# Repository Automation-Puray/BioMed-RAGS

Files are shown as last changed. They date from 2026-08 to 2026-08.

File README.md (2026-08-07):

# BioMed-RAGS

**A Low-Cost Open-Source Robotic Platform for Automated Optical Characterization of Complex Light Emitters**

> **Repository status:** This is a public pre-release repository. Hardware files, software, datasets, and supporting documentation are being reviewed and added progressively. The first complete versioned research release is not yet available.

## Overview

BioMed-RAGS is a low-cost, modular robotic platform for repeatable, spatially resolved characterization of optical emitters with different geometries. It supports cylindrical axial-azimuthal measurements and planar raster measurements using programmable scan paths and interchangeable detectors.

In the demonstrated configuration, a robotic arm and linear rail provide four controlled degrees of freedom for detector positioning. Two synchronized rotational stages provide a coordinated specimen-rotation axis for cylindrical measurements. The Python software coordinates motion, spectral acquisition, HDF5 data storage, processing, and visualization.

Device-specific drivers separate the measurement logic from the connected hardware, allowing sensors or motion components to be changed without rebuilding the complete control workflow.

## Demonstrated applications

The platform was evaluated using:

- Two light-diffusing fiber constructions for photodisinfection research
- A planar resin-printer backlight measured at multiple drive settings
- A bioreactor tube irradiance-mapping application example

## Key capabilities

- Automated cylindrical axial-azimuthal scanning
- Automated planar raster scanning
- Spatially resolved spectral-irradiance measurements
- Programmable scan ranges and step sizes
- Automatic spectrometer exposure adjustment
- Synchronized motion and spectral acquisition
- HDF5 storage of spectra and measurement coordinates
- Modular hardware-driver architecture
- Automated data processing and visualization
- Repeatability and reproducibility analysis

## Reported performance

| Measurement | Reported result |
|---|---:|
| Fiber peak irradiance, combined RSD | 1.21% (95% CI: 0.85–1.65%) |
| Planar area-mean irradiance, combined RSD | 0.78% (95% CI: 0.48–2.04%) |
| Fiber decay constant, combined RSD | 0.52% |
| Spectral peak stability across one 336-point scan | 0.06 nm |

These results describe the precision of the demonstrated measurement system. The study primarily evaluates repeatability and reproducibility rather than independent verification of absolute irradiance accuracy.

## Demonstrated configuration and cost

The demonstrated system uses a robotic arm on a 1000 mm linear rail, two synchronized rotational stages, a Raspberry Pi controller, and a spectrometer probe with a cosine corrector.

The automation layer used in this implementation cost approximately **USD 2,200**. This value is specific to the selected hardware and may change with component choice. The spectrometer, excitation source, and shared laboratory instruments are not included in this automation-layer estimate.

## Repository contents

| Directory | Contents |
|---|---|
| [`hardware/`](hardware/) | Bill of materials, mechanical designs, assembly photographs, and electronics documentation |
| [`firmware/`](firmware/) | Firmware and setup information for the rotational stages |
| [`software/`](software/) | Measurement-control and data-analysis software |
| [`data/`](data/) | Measurement datasets and processed results |
| [`docs/`](docs/) | Build, operation, calibration, and uncertainty documentation |
| [`examples/`](examples/) | Additional application examples and associated analyses |

These directories are currently being populated. Refer to the README inside each directory for its planned organization.

## Associated publication

This repository accompanies the manuscript:

> *A Low-Cost Open-Source Robotic Platform for Automated Optical Characterization of Complex Light Emitters*

The complete citation, DOI, and publication link will be added when they become available.

## Safety

This research platform includes moving robotic equipment and optical radiation sources. Appropriate laser or UV eye protection, beam control, access restriction, electrical precautions, and mechanical risk controls must be established before operation. Read the complete [platform safety guidance](SAFETY.md) before assembling or operating the system.

This repository does not replace a laboratory-specific risk assessment or the operating instructions supplied by equipment manufacturers.

## Credits and acknowledgements

The robotic arm control in this project uses the **pydexarm** Python library to communicate with the Rotrics DexArm. The DexArm firmware is built on [**Marlin**](https://marlinfw.org/), the open-source 3D-printer firmware project. DexArm firmware is fully open-source and its control commands (G-code) are compatible with Marlin.

- Marlin firmware: [marlinfw.org](https://marlinfw.org/) — GNU General Public Licence
- Rotrics DexArm: [rotrics.com](https://rotrics.com)
- pydexarm library: [github.com/Rotrics-Dev/pydexarm](https://github.com/Rotrics-Dev/pydexarm)

We thank the Marlin and Rotrics communities for making open robotic hardware accessible to research laboratories.

## License and citation

License files and `CITATION.cff` metadata are being prepared and will be included before the first complete versioned release.

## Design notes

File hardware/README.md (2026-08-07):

# Hardware

This directory contains the BioMed-RAGS bill of materials, mechanical design files, assembly photographs, and electronics documentation.

Planned organization:

- BOM/ — bill of materials
- mechanical/CAD/ — printable parts and assembly models
- mechanical/assembly_photos/ — approved assembly photographs
- electronics/ — wiring and electronic-component documentation

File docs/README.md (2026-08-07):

# Documentation

This directory contains the BioMed-RAGS build, operation, calibration, and measurement-uncertainty documentation.

Planned organization:

- `build_guide/`
- `SOP/`
- `calibration/`
- `uncertainty_budget.pdf`

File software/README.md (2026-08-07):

# Software

This directory contains the BioMed-RAGS measurement-control and data-analysis software.

The software will be organized into:

- `control/` — measurement control, hardware drivers, data storage, and calibration
- `analysis/` — data processing, precision analysis, and visualization

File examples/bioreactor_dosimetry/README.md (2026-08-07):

# Bioreactor dosimetry example

This directory will contain the approved example data and analysis materials for the bioreactor dosimetry application.

# Bioreactor tube dosimetry

The planar scanning workflow was applied to evaluate two different serpentine glass-tube configurations for a bioreactor using two 222 nm excimer lamps. Both tubes had a 4 mm outer diameter but followed different paths across the irradiated area.

A 220 × 160 mm irradiance field was measured over the 200–240 nm band at 2 × 2 mm resolution and a 10 mm standoff. The measured field was then registered to the CAD-defined centreline of each tube to estimate the irradiance experienced along its path.

The first tube had an evaluated path length of 1366 mm and a mean centreline irradiance of 686 µW/cm². The second tube had an evaluated path length of 1254 mm and a mean centreline irradiance of 780 µW/cm². This application demonstrates how the same planar measurement can be combined with different tube geometries to produce design-specific optical-dose information.

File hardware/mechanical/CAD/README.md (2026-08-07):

# Mechanical CAD files

This directory contains the mechanical design files for the BioMed-RAGS platform.

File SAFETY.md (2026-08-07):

# Safety

BioMed-RAGS is a research platform containing motorized equipment, electrical components, and optical radiation sources. It must be operated only by trained personnel following the applicable institutional risk assessment, local safety procedures, and manufacturer instructions.

The information in this document does not replace source-specific laser or UV safety assessment, laboratory training, or equipment manuals.

## Main hazards

The principal hazards include:

- Direct or reflected exposure to laser or ultraviolet radiation
- Eye or skin exposure during alignment, mounting, or testing
- Pinch, impact, and entanglement hazards from the robotic arm, linear rail, and rotational stages
- Unexpected motion caused by incorrect coordinates, units, limits, or software configuration
- Electrical hazards from power supplies, controllers, motors, and modified wiring
- Movement or release of an incorrectly secured specimen, detector, fixture, or cable

## Before operation

Before starting a measurement:

1. Identify the wavelength, optical power, operating mode, and hazard classification of the installed source.
2. Complete a risk assessment appropriate to the source and experimental configuration.
3. Restrict access to the measurement area as required by laboratory procedures.
4. Inspect the robot, rail, stages, fixtures, fasteners, wiring, and cables for damage or insecure connections.
5. Confirm that the specimen and detector are securely mounted.
6. Verify the coordinate system, scan limits, step direction, standoff distance, and expected motion.
7. Perform a low-speed dry run with the optical source disabled.
8. Confirm that an accessible method is available to stop motion and disconnect power.
9. Remove loose objects from the motion area and secure loose clothing, hair, and cables.
10. Do not leave the operating system unattended unless the laboratory risk assessment explicitly permits it.

## Optical radiation safety

The demonstrated applications include a 405 nm diode laser and measurements involving 222 nm excimer lamps. Direct or reflected optical radiation may cause eye or skin injury. Far-UVC radiation must not be assumed to be harmless.

Apply controls appropriate to the installed source, which may include:

- Enclosing or shielding the optical path
- Terminating beams with a suitable beam stop
- Preventing unintended reflections
- Restricting access during operation
- Using interlocks where required
- Monitoring the experiment remotely
- Wearing eye or skin protection selected for the wavelength and exposure level

Protective eyewear must have a wavelength range and optical density appropriate to the specific source. Eyewear does not replace enclosure, shielding, access control, or other engineering controls.

Switch off or otherwise make the optical source safe before installing, removing, or adjusting a specimen or detector. Alignment with an active source should be performed only under an approved alignment procedure.

## Robotic and mechanical safety

The robotic arm, linear rail, and rotational stages can create pinch, impact, and entanglement hazards.

- Keep hands and other objects outside the motion envelope while the system is enabled.
- Disable motion and disconnect power before adjusting fixtures or mechanical components.
- Do not exceed the travel, speed, payload, or operating limits specified by the equipment manufacturers.
- Secure specimens at both ends before operating the rotational stages.
- Route cables so they cannot become trapped, stretched, or wound around moving components.
- Use conservative speeds during setup and after any hardware or software change.

The demonstrated rotational stages operate open loop. A missed motor step may not be detected automatically. Verify the mechanical reference position before a scan and after any unexpected interruption or collision.

## Software and motion configuration

Software limits are not physical guards.

Before enabling automated motion:

- Check that all coordinates use the intended units and reference frame.
- Confirm minimum and maximum positions for every axis.
- Check the sign and direction of each step value.
- Confirm that the programmed path cannot contact the specimen, fixtures, optical table, or nearby equipment.
- Test the stop procedure before the first active measurement.
- Repeat the dry run after changing fixtures, detectors, scan geometry, or control software.

Stop the system immediately if movement differs from the expected path.

## Electrical safety

- Disconnect power before modifying wiring or electronics.
- Do not operate the system with exposed conductors or damaged cables.
- Use suitable power supplies, protective enclosures, connectors, strain relief, and overcurrent protection.
- Follow the grounding and installation requirements provided by each equipment manufacturer.
- Electrical modifications should be performed only by personnel qualified for the work.

## Incident response

If unintended exposure, collision, electrical failure, mechanical damage, or abnormal motion occurs:

1. Stop motion and disable the optical source.
2. Disconnect power when it is safe to do so.
3. Prevent further access to the affected equipment.
4. Follow the laboratory incident and medical-response procedures.
5. Inspect and revalidate the system before returning it to operation.

Report safety-related repository issues without including personal, confidential, or security-sensitive information.

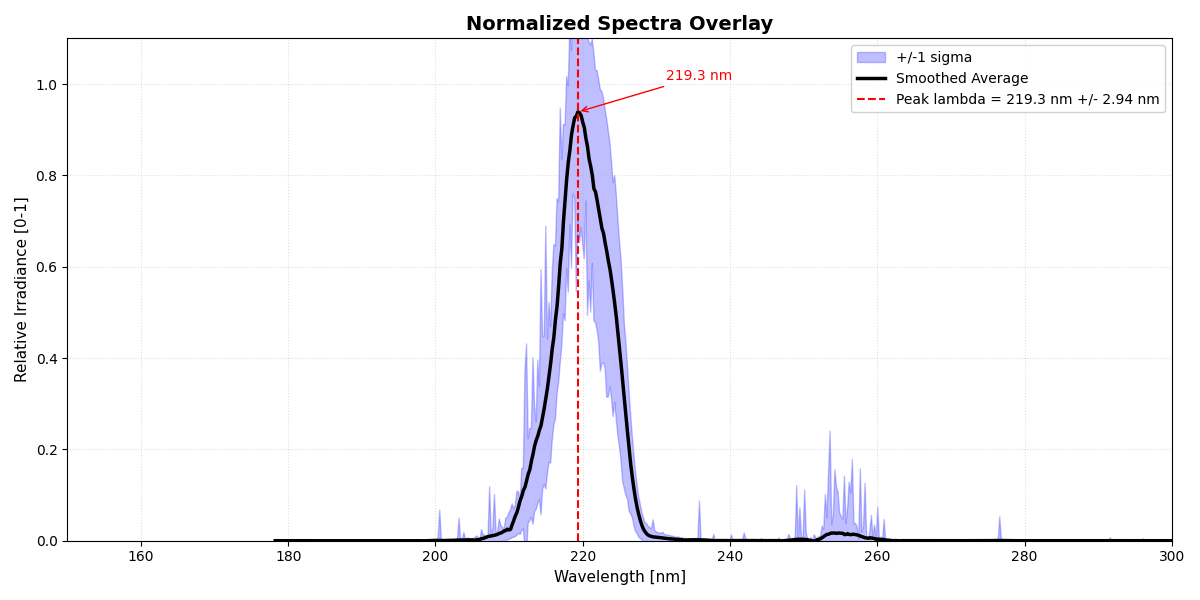
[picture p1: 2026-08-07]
examples/bioreactor_dosimetry/2x2_Spectral_Overlay.png

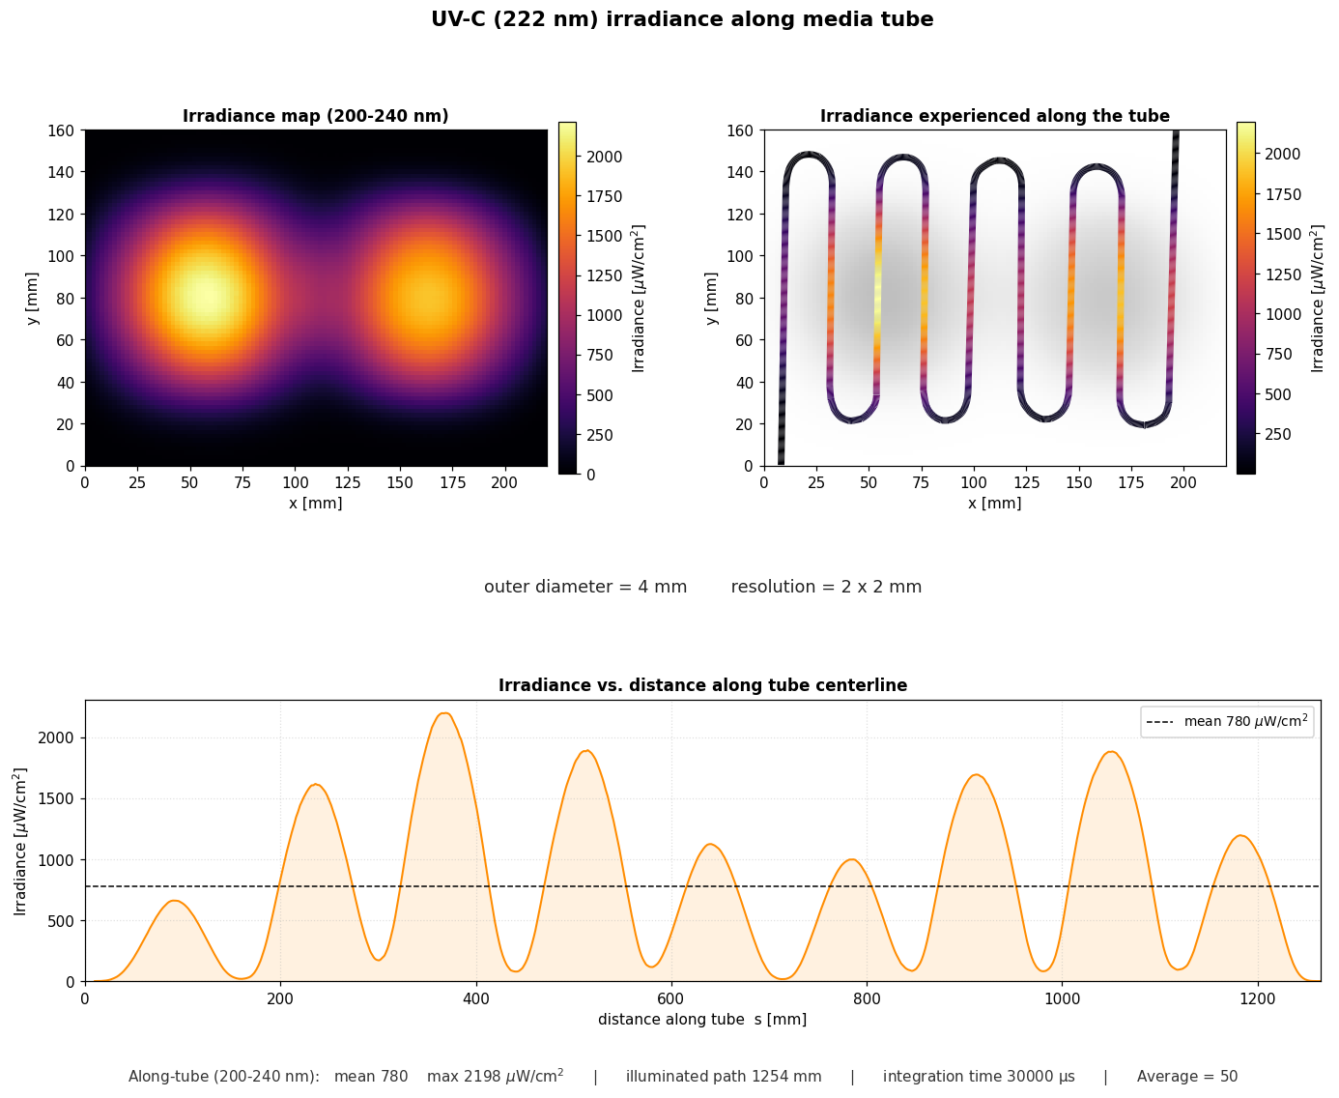
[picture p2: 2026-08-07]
examples/bioreactor_dosimetry/2x2_Plate_2.png

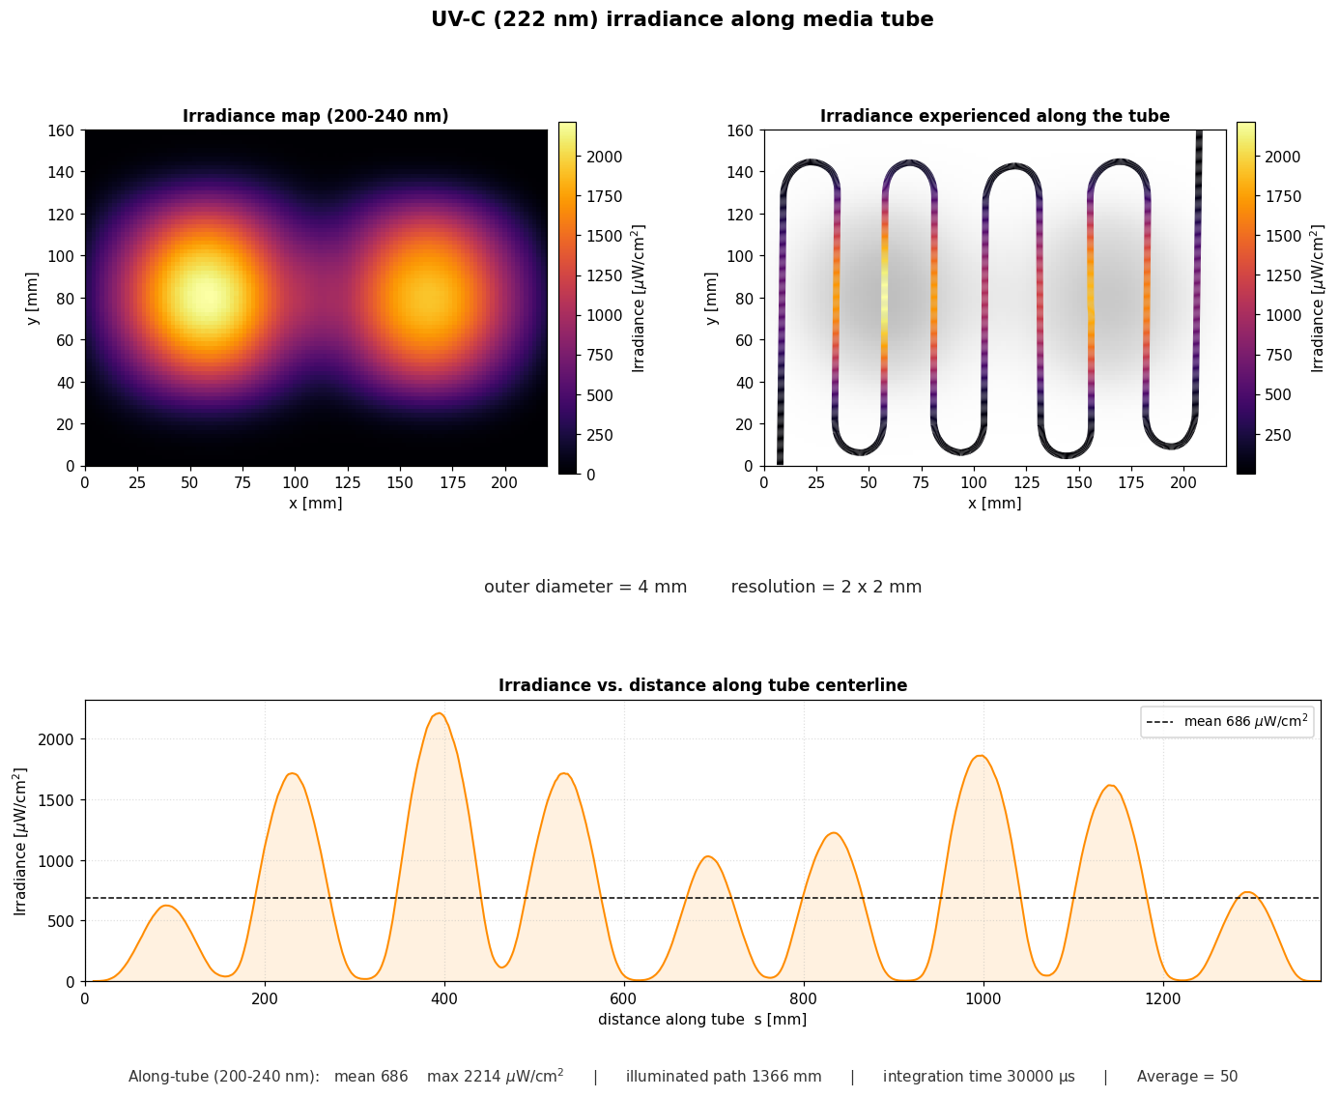
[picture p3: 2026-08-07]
examples/bioreactor_dosimetry/2x2_Plate_1.png

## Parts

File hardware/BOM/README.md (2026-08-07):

Bill of Materials

The Excel BOM lists the components and approximate 2025-2026 costs for the demonstrated BioMed-RAGS configuration.

Cost context

The full-system total is not a minimum build cost. The new automation hardware in the demonstrated setup costs approximately USD 2,200. Actual reproduction costs depend on the equipment already available and the hardware selected.

Many optics and engineering laboratories may already have common components such as:

a calibrated spectrometer;

an optical breadboard;

a laser source;

optical posts and mounts;

a power meter or integrating sphere;

controller boards or a single-board computer; and

access to a 3D printer.

Users may select compatible lower-cost robots, rails, rotation stages, controllers, frames, mounts, and optical components according to the required travel range, load, precision, and measurement geometry.

Any substitute detector, fiber probe, or cosine corrector should be calibrated and verified for spectral range, sensitivity, angular response, and measurement geometry.

Prices are approximate, exclude shipping and taxes, and may vary by supplier, region, and purchase date.

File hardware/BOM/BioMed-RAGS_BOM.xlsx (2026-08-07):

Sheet: Cost Notes
BioMed-RAGS Cost Summary and Notes
Cost scope | Amount (USD) | Definition
Automation hardware | $2215 | Robot, rail, controllers, and two rotation stages
Other core components | $8697 | Structure, detector, interfaces, and fabricated parts
Core system total | $10912 | Automation hardware + other core components
Shared lab instruments | $4480 | Laser and launch-power measurement equipment
Optional equipment | $400 | Environmental monitoring
Full listed system | $15792
Guidance |  | Details
Displayed total |  | The full-system total represents the demonstrated configuration, not a minimum build cost. The new automation hardware is approximately $2,200.
Commonly reusable |  | Many optics and engineering laboratories may already have a calibrated spectrometer, optical breadboard, laser source, optical posts and mounts, power meter or integrating sphere, controller boards, and access to a 3D printer.
Compatible alternatives |  | Users may select lower-cost robots, rails, rotation stages, controllers, frames, mounts, and compatible optical components according to the required travel range, load, precision, and measurement geometry.
Calibration requirement |  | Any substitute detector, fiber probe, or cosine corrector should be calibrated and verified for spectral range, sensitivity, angular response, and measurement geometry.

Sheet: BOM
BioMed-RAGS Bill of Materials
Cost note | Illustrative demonstrated configuration; approximate 2025-2026 costs in USD. Reuse and compatible alternatives can reduce the actual build cost.
ID | Category | Component | Manufacturer / Brand | Model / Part No. | Purpose / Key Note | Qty | Unit Cost (USD) | Total Cost (USD) | Cost Class
1 | Motion and control | Desktop robotic arm | Rotrics | DexArm | Four-axis detector positioning | 1 | $1100 | $1100 | Automation hardware
2 | Motion and control | Linear rail extension | Rotrics | Linear Rail 1000 mm | Extends robot travel to 1000 mm | 1 | $900 | $900 | Automation hardware
3 | Motion and control | Single-board computer | Raspberry Pi Foundation | Raspberry Pi 4B (4 GB) | Runs the Python control software | 1 | $75 | $75 | Automation hardware
4 | Motion and control | Microcontroller | Arduino | Uno Rev3 | One controller per rotation stage | 2 | $25 | $50 | Automation hardware
5 | Motion and control | Proximal rotation stage | DIY / generic | NEMA 11 stepper + driver | Motorized rotation at the laser-coupling end | 1 | $45 | $45 | Automation hardware
6 | Motion and control | Distal rotation stage | DIY / generic | NEMA 11 stepper + driver | Motorized rotation at the fiber-support end | 1 | $45 | $45 | Automation hardware
7 | Structure and mounting | Aluminium extrusion frame | Generic | 30-series extrusion | Rigid base frame; cut to CAD dimensions | 1 | $80 | $80 | Other core components
8 | Structure and mounting | Optical breadboard | Thorlabs / equivalent | 900 x 450 mm; M6, 25.4 mm grid | Mounting platform for the system | 1 | $630 | $630 | Other core components
9 | Structure and mounting | Proximal stage post | Thorlabs | RA90 / TR-series | Sets the proximal stage at the fiber-axis height | 1 | $30 | $30 | Other core components
10 | Structure and mounting | Distal stage post | Thorlabs | RA90 / TR-series | Sets the distal stage at the fiber-axis height | 1 | $30 | $30 | Other core components
11 | Optical detection | Spectrometer | Ocean Insight | FLAME-T-UV-VIS-ES | Radiometrically calibrated spectral detection, 200-850 nm | 1 | $7300 | $7300 | Other core components
12 | Optical detection | Optical fiber probe | Ocean Insight | QP400-2-SR-BX | Connects the cosine corrector to the spectrometer | 1 | $280 | $280 | Other core components
13 | Optical detection | Cosine corrector | Ocean Insight | CC-3-UV-S | Irradiance collection with cosine response | 1 | $245 | $245 | Other core components
14 | Optical detection | Probe bracket | In-house / 3D printed | probe_bracket.stl | Fixes the cosine corrector to the robot end effector | 1 | $5 | $5 | Other core components
15 | Shared excitation equipment | CW diode laser, 405 nm | BWT Beijing / equivalent | BWB-405-8000m | Fiber excitation source; shared laboratory instrument | 1 | $3000 | $3000 | Shared lab instruments
16 | Shared excitation equipment | Power meter console | Thorlabs | PM400 | Launch-power verification; shared laboratory instrument | 1 | $1140 | $1140 | Shared lab instruments
17 | Shared excitation equipment | Integrating sphere sensor head | Thorlabs | S142C | Used with the PM400; shared laboratory instrument | 1 | $340 | $340 | Shared lab instruments
18 | Fiber interface | FC-to-SMA adapter | Thorlabs / equivalent | ADAFCSMA1 | Couples the laser pigtail to the test fiber | 1 | $35 | $35 | Other core components
19 | Fiber interface | Fiber clamp | Thorlabs | SM1F1-250 | Secures the distal end of the test fiber | 1 | $50 | $50 | Other core components
20 | Environmental monitoring | Environmental sensor | Corant GmbH (air-Q) | air-Q Pro | Optional temperature and humidity logging | 1 | $400 | $400 | Optional equipment
21 | Fabricated parts | Proximal stage adapter disc | In-house / 3D printed | fiber_disc_proximal.stl | Centers the ADAFCSMA1 adapter on the rotation axis | 1 | $2 | $2 | Other core components
22 | Fabricated parts | Holder clips and cable guides | In-house / 3D printed | Various | Small mounting and cable-management parts | 1 | $10 | $10 | Other core components
 |  |  |  |  |  |  | Full listed system | $15792

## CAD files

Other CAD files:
hardware/mechanical/CAD/Spektrometer Rotrics Adapter - Top - Well Adapter V2.f3z

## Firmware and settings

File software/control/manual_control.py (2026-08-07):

# /home/Biomed/fiber_gonio/Refactor/devices/manual_control.py

import asyncio
import sys
import logging
import time
from datetime import datetime
from Refactor.devices.dexarm_controller import DexArmController
from Refactor.devices.measurement_routine import MeasurementLoop
from Refactor.devices.server_api_client import ServerAPIClient
from Refactor.devices.airq import AirQClient

MOVE_STEPS = [200, 100, 50, 20, 10, 5, 1]


def _get_key_sync():
    try:
        import msvcrt
        if msvcrt.kbhit():
            ch = msvcrt.getch()
            if ch in (b"\x00", b"\xe0"):
                ch = msvcrt.getch()
                return {b"H": "UP", b"P": "DOWN", b"K": "LEFT", b"M": "RIGHT"}.get(ch, "")
            return "ENTER" if ch == b"\r" else ch.decode()
        return None
    except ImportError:
        import tty, termios
        fd = sys.stdin.fileno()
        old = termios.tcgetattr(fd)
        try:
            tty.setraw(fd)
            c = sys.stdin.read(1)
            if c == "\x03":
                raise KeyboardInterrupt
            if c == "\x1b":
                seq = sys.stdin.read(2)
                return {"[A": "UP", "[B": "DOWN", "[C": "RIGHT", "[D": "LEFT"}.get(seq, "")
            return "ENTER" if c in ("\r", "\n") else c
        finally:
            termios.tcsetattr(fd, termios.TCSADRAIN, old)


async def get_key():
    loop = asyncio.get_running_loop()
    return await loop.run_in_executor(None, _get_key_sync)


def _get_manual_coord_sync():
    try:
        logging.info("Enter manual coordinates (leave blank to skip an axis):")
        x = input("X: ")
        y = input("Y: ")
        z = input("Z: ")
        x = float(x) if x.strip() else None
        y = float(y) if y.strip() else None
        z = float(z) if z.strip() else None
        return x, y, z
    except ValueError:
        logging.info("Invalid input.")
        return _get_manual_coord_sync()


async def get_manual_coord():
    loop = asyncio.get_running_loop()
    return await loop.run_in_executor(None, _get_manual_coord_sync)


class ManualDexArmController:
    def __init__(
        self,
        dexarm: DexArmController,
        mode="system",
        laser_control=None,
        pm400=None,
        spectrometer=None,
        arduino_stage=None,
        experiment_data=None,
        hdf5_manager=None,
        initial_laser_setpoint=None,
        laser_source="",
        category="single",
        lte_params=None # New: Pass {duration, interval, num_cycles} here
    ):
        self.dexarm = dexarm
        self.x, self.y, self.z_offset = None, None, None
        self.step_index = MOVE_STEPS.index(20)
        self.mode = mode
        self.measurement_routine = MeasurementLoop(
            self.dexarm,
            arduino_stage,
            spectrometer,
            laser_control,
            pm400,
            experiment_data=experiment_data,
            laser_source=laser_source,
        )
        self.laser_control = laser_control
        self.pm400 = pm400
        self.limits_enabled = True
        self.hdf5_manager = hdf5_manager
        self.experiment_data = experiment_data if experiment_data is not None else {}
        self.spectrometer = spectrometer
        self.initial_laser_setpoint = initial_laser_setpoint
        self.category = category
        self.airq = AirQClient()

        # LTE parameters passed from main.py
        if lte_params:
            self.lte_duration_min = lte_params.get('duration', 0)
            self.lte_interval_min = lte_params.get('interval', 0)
            self.lte_num_cycles = lte_params.get('num_cycles', 0)
        else:
            self.lte_duration_min = 0
            self.lte_interval_min = 0
            self.lte_num_cycles = 0

    def is_safe(self, x, y, z_offset):
        if not self.limits_enabled:
            return True
        if self.mode == "experiment":
            return self.dexarm.boundary_manager.is_position_safe(x, y, z_offset)
        else:
            return self.dexarm.boundary_manager.is_within_hard_limits(x, y, z_offset)

    async def move_by(self, dx=0, dy=0, dz=0):
        if self.x is None or self.y is None or self.z_offset is None:
            current_x, current_y, current_z = await self.dexarm.get_translated_position()
            self.x, self.y, self.z_offset = current_x, current_y, current_z - 300

        step = MOVE_STEPS[self.step_index]
        new_x = self.x + dx * step
        new_y = self.y + dy * step
        new_z_offset = self.z_offset + dz * step

        if self.is_safe(new_x, new_y, new_z_offset):
            await self.dexarm.move_to(new_x, new_y, new_z_offset)
            self.x, self.y, self.z_offset = new_x, new_y, new_z_offset
        else:
            logging.info(f"Out of bounds. Rejected: X={new_x:.1f}, Y={new_y:.1f}, Z={new_z_offset:.2f}")

    async def manual_coord_move(self):
        x_input, y_input, z_input_offset = await get_manual_coord()
        if self.x is None or self.y is None or self.z_offset is None:
            current_x, current_y, current_z = await self.dexarm.get_translated_position()
            self.x, self.y, self.z_offset = current_x, current_y, current_z - 300
        new_x = x_input if x_input is not None else self.x
        new_y = y_input if y_input is not None else self.y
        new_z_offset = z_input_offset if z_input_offset is not None else self.z_offset
        if self.is_safe(new_x, new_y, new_z_offset):
            await self.dexarm.sequential_move_xyz(
                x=new_x, y=new_y, z=new_z_offset, safety_override=not self.limits_enabled,
            )
            self.x, self.y, self.z_offset = new_x, new_y, new_z_offset
        else:
            logging.info(f"Out of bounds. Rejected: X={new_x:.1f}, Y={new_y:.1f}, Z={new_z_offset:.2f}")

    def change_step(self):
        self.step_index = (self.step_index + 1) % len(MOVE_STEPS)
        logging.info(f"Step size set to {MOVE_STEPS[self.step_index]} mm")

    def get_current_bounds(self):
        experiment_name = self.dexarm.boundary_manager.current_experiment_name
        if experiment_name:
            return self.dexarm.boundary_manager.experiment_profiles.get(experiment_name)
        return None
    
    async def capture_environment(self):
        try:
            return await self.airq.get_conditions()
        except:
            return None, None

    async def run_single_cycle(self, cycle_index):
        """
        Executes one measurement cycle and guarantees that
        spectrometer data is persisted to HDF5.
        """

        cycle_data = {}

        # ---- HEADER ----
        if self.category == "long_term":
            logging.info(f"STARTING LONG-TERM MEASUREMENT: CYCLE {cycle_index + 1} / {self.lte_num_cycles}")
            logging.info("-" * 50)
        else:
            logging.info("STARTING EXPERIMENT")
            logging.info("-" * 50)
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

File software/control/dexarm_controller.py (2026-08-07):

# /home/Biomed/fiber_gonio/Refactor/devices/dexarm_controller.py
import os
import logging
import asyncio 
import functools
from DexArm_API.pydexarm import Dexarm
from Refactor.devices.robot_limits import RobotBoundaryManager, CALIBRATION_JSON_PATH

DEFAULT_DEXARM_PORT = "/dev/ttyACM0"

def unpack_xyz(raw):
    """
    DexArm returns (x, y, z, e, a, b, c)
    User coords:
    - X = E  (DexArm extrusion axis)
    - Y = Z  (DexArm vertical axis)
    - Z = Y  (DexArm sliding rail axis)
    """
    return raw[3], raw[2], raw[1]

def pack_xyz(x, y, z):
    """
    Convert user coords to DexArm internal coords:
    - e = X (left/right)
    - z = Y (up/down)
    - y = Z (forward/back)
    """
    return {"e": x, "y": z, "z": y}

class DexArmController:
    def __init__(self, port=DEFAULT_DEXARM_PORT, config_path=CALIBRATION_JSON_PATH):
        self.dex = Dexarm(port)
        self.boundary_manager = RobotBoundaryManager(config_path)

        if self.dex.is_open:
            logging.info(f"DexArm serial port established: {port}")
        else:
            logging.error(f"Failed to open DexArm serial port: {port}")
    
    async def _run_blocking(self, func, *args, **kwargs):
        """Helper to run blocking pydexarm methods in a separate thread."""
        loop = asyncio.get_running_loop()
        # Use functools.partial to create a callable that can be executed by the executor
        return await loop.run_in_executor(None, functools.partial(func, *args, **kwargs))
    
    async def initialize(self):
        #logging.info("Initializing sliding rail...")
        await self._run_blocking(self.dex.sliding_rail_init)
        await asyncio.sleep(3)

        #logging.info("Homing DexArm...")
        await self.home_dexarm()
        await asyncio.sleep(2)

        #logging.info("Setting work origin...")
        await self._run_blocking(self.dex.set_workorigin)
        logging.info("DexArm initialized.")

    

    async def home_dexarm(self):
        #logging.info("Homing DexArm and resetting X (e=0)...")
        await self._run_blocking(self.dex.go_home)
        await self._run_blocking(self.dex.move_to, e=0)

    def set_experiment(self, name: str):
        self.boundary_manager.set_experiment(name)
        #logging.info(f"Experiment bounds loaded: {name}")

    async def move_to(self, x=None, y=None, z=None, feedrate=2000,partial=False):
        coords = pack_xyz(x, y, z)
        await self._run_blocking(self.dex.move_to, **coords, feedrate=feedrate)
        if not partial:
            
            logging.info(f"Moved to : x={x}, y={y}, z={z}")

    async def fast_move_to(self, x=None, y=None, z=None, feedrate=3000):
        coords = pack_xyz(x, y, z)
        await self._run_blocking(self.dex.fast_move_to, **coords, feedrate=feedrate)
        logging.info(f"Fast moved to (user coords): x={x}, y={y}, z={z}")
        

    async def safe_move_to(self, x=None, y=None, z=None, feedrate=2000,partial=False, safety_override=False):
        current = await self.get_translated_position()
        target_x = x if x is not None else current[0]
        target_y = y if y is not None else current[1]
        target_z = z if z is not None else (current[2] - 300.0)
        

        if (not safety_override) and (not self.boundary_manager.is_position_safe(target_x, target_y, target_z)):
            logging.warning("Unsafe target position. Moving to SAFE_PARK_COORDINATES.")
            coords = self.boundary_manager.get_safe_park_coordinates()
            sx, sy, sz = coords['x'], coords['y'], coords['z']
            sx, sy, sz = float(sx), float(sy), float(sz)
            await self.move_to(x=sx, y=sy, z=sz)
            return False

        await self.move_to(x=x, y=y, z=z, feedrate=feedrate,partial=partial)
        return True

    async def get_position(self):
        pos = await self._run_blocking(self.dex.get_current_position)
        logging.info(f"Current DexArm position (raw): {pos}")
        return pos

    async def get_translated_position(self):
        raw = await self._run_blocking(self.dex.get_current_position)
        x, y, z = unpack_xyz(raw)
        #logging.info(f"Translated position (Robot coords): x={x}, y={y}, z={z}")
        return x, y, z


    async def sequential_move_xyz(self, x=None, y=None, z=None, feedrate=2000, safety_override=False):
        #logging.info(f"Sequentially moving to: x={x}, y={y}, z={z}")

        # Step 1: Move X-axis (keep other targets unchanged)
        if x is not None:
            if not await self.safe_move_to(x=x, y=None, z=None, feedrate=feedrate, partial=True, safety_override=safety_override):
                return False
            await asyncio.sleep(1)

        # Step 2: Move Y-axis
        if y is not None:
            if not await self.safe_move_to(x=x, y=y, z=None, feedrate=feedrate, partial=True, safety_override=safety_override):
                return False
            await asyncio.sleep(1)

        # Step 3: Move Z-axis
        if z is not None:
            if not await self.safe_move_to(x=x, y=y, z=z, feedrate=feedrate, safety_override=safety_override):
                return False
            await asyncio.sleep(1)

        return True


    async def move_to_experiment_entry(self, x=None, y=None, z=None, feedrate=2000):
        """
        Move from outside the experiment envelope into the experiment start point.

        Intermediate waypoints are checked only against HARD limits so the robot
        can travel from Home into the saved experiment boundary.

        The final target must still satisfy the normal experiment safety check.
        """
        current_x, current_y, current_z_raw = await self.get_translated_position()
        current_z_offset = current_z_raw - 300.0

        target_x = x if x is not None else current_x
        target_y = y if y is not None else current_y
        target_z = z if z is not None else current_z_offset

        # Final target must still be fully safe:
        # hard limits + experiment bounds
        if not self.boundary_manager.is_position_safe(target_x, target_y, target_z):
            logging.warning(
                f"Experiment start position is unsafe: x={target_x}, y={target_y}, z={target_z}"
            )
            coords = self.boundary_manager.get_safe_park_coordinates()
            sx, sy, sz = float(coords["x"]), float(coords["y"]), float(coords["z"])
            await self.move_to(x=sx, y=sy, z=sz)
            return False

        # Step 1: Move X using HARD limits only
        if x is not None:
            if not self.boundary_manager.is_within_hard_limits(target_x, current_y, current_z_offset):
                logging.warning(
                    f"Experiment entry X-step violates hard limits: "
                    f"x={target_x}, y={current_y}, z={current_z_offset}"
                )
                return False

            await self.move_to(x=x, y=None, z=None, feedrate=feedrate, partial=True)
            await asyncio.sleep(1)
            current_x = target_x
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

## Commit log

2026-08-07 Create mechanical CAD directory
2026-08-07 Add mechanical CAD files
    [Spektrometer Rotrics Adapter - Top - Well Adapter V2.f3z]
2026-08-07 Add credits and acknowledgements section to README
    Added credits and acknowledgements section detailing the use of the pydexarm library and Marlin firmware.
2026-08-07 Add README for Bill of Materials
    Added a README file for the Bill of Materials detailing components and costs for the BioMed-RAGS configuration.
2026-08-07 Enhance README with bioreactor tube dosimetry details
    Added detailed explanation of bioreactor tube dosimetry and its evaluation.
2026-08-07 Create Supplementary Material
